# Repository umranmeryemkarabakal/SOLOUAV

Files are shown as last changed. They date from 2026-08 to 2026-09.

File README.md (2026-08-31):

# Tilt-Rotor VTOL — INDI + LESO + WLS Kontrolcü (MATLAB/Simulink)

3 tilt-rotorlu bir VTOL aracı (2 kanat rotoru + 1 kuyruk rotoru) için
**INDI (Incremental Nonlinear Dynamic Inversion)** tabanlı tutum kontrolcüsü,
**LESO** (Lineer Genişletilmiş Durum Gözlemcisi) ile bozucu telafisi,
**WLS** (ağırlıklı en küçük kareler) kontrol tahsisi ve tilt açısına bağlı
basit **gain-scheduling** içeren tam bir simülasyon paketi.

Depo iki paralel uygulama barındırır:

| | Saf MATLAB | Simulink |
|---|---|---|
| Kontrolcü | `indi_attitude_controller.m` | `sf_indi_rate_law.m` + `sf_wls_alloc.m` |
| Plant | `tiltrotor_plant_deriv.m` + `rk4_step.m` | `tiltrotor_plant_sfcn.m` (Level-2 S-Function) |
| Koşturma | `run_hover_gust_test.m`, `run_transition_test.m` | `tiltrotor_indi.slx` (`tiltrotor_indi_build.m` ile üretilir) |

İkisi de **aynı matematiği** uygular; Simulink tarafındaki `sf_*.m` dosyaları
MATLAB Function bloğunun kod üretimi kısıtlarına (değişken boyut yok,
`persistent` yok) göre yeniden yazılmış sürümlerdir.

---

## ► GÜNCEL DURUM (2026-08-31, Adım 152)

Bu README'nin gövdesi Adım ~39'da (3 Ağustos) donmuştur ve kontrolcü
mimarisini hâlâ doğru anlatır. Aşağıdaki blok o tarihten sonrasını özetler;
adım adım kayıt `WLS_LOCKUP_INVESTIGATION_REPORT.md`'dedir.

### Ne çalışıyor

Tam görev SITL'de uçuyor: **kalkış → ileri geçiş → sabit kanat (90° tilt,
~14,5 m/s) → geri geçiş → hover → iniş**, sakin ve rüzgârlı dünyada.
MATLAB regresyon 12/12, kod üretimi paritesi TEST A–F tam (0 mekanizma
eksik), üretilen kod kaynakla tutarlı, Cube Orange derleniyor (flash %84,5).

### Geometri (2026-08-31 itibarıyla)

| | değer |
|---|---|
| Ön rotorlar | x **+0,27**, y **±0,35**, z −0,11 |
| Kuyruk rotoru | x **−0,55**, z −0,07, tilt **0–20°** |
| Fin / rudder / çubuk | −0,78 / −0,87 / 0,71 m |

Ön naseller kanadın hücum kenarının **önüne** alındı: 90° tiltte pervane
diski dikey bir düzlemdir ve göbek hücum kenarının gerisindeyse kanadı keser.
Pervaneyi küçültmek, açıklıkta dışa almak ve tilt'i sınırlamak **ölçülüp
elendi** (Adım 143).

### ⚠ En büyük açık: kartta İNİŞ YOLU YOK

Modül `z_sp`'yi **dışarıdan** alır (`tiltrotor_indi_setpoint`) ya da manuel
gaz kolundan. İniş **dizisi** (kademeli alçalma, flare, temas, motor kesme)
`sitl/run_mission_test.py` içindedir — yani PC tarafında.

O betik hedefi `px4-mc_indi_tiltrotor test_sp` **POSIX kabuk istemcisiyle**
gönderir; bu yol yalnızca SITL'de vardır. Gerçek kartta karşılığı yoktur ve
`flight_mode_manager`/`mc_pos_control` bu airframe'de **bilerek durdurulur**
(yoksa iki modül aynı anda aktüatörlere yazar), yani PX4'ün kendi land modu
da devrede değildir.

**Sonuç: kart bugün flash edilirse otonom iniş olmaz.** Kartta tek yol
manuel gaz koludur (`_man_z_sp`) ve o da RC yoluna bağlıdır — madde H8,
**henüz sınanmadı**. Ayrıntı: `HARDWARE_READINESS_CHECKLIST.md`.

### Bu oturumda eklenen korumalar

- `LAND_TZ_MAX` — iniş kapısı altında tahsisat, komut edilen dikey kuvvetin
  2 katından fazlasını üretemez. Temas sonrası kuyruk 0 N'e dayanınca ön
  itkinin aracı geri kaldırmasını keser (ölçülen sıçrama 0,84 m).
- **Yer etkisi harmanı** — `lpos.vz`'nin yere yakın +0,4 m/s kalıcı sapması
  var (baro, rotor akışıyla basınçlanıyor) ve komut edilen alçalma hızını
  birebir iptal ediyordu. Yerde `z_deriv` ile harmanlanır.
- Kapılara üç denetim: gerçek mesh açıklığı, XML yorum, **köke bağlantı**
  (fin 20 mm havada asılıydı, hiçbir kapı görmüyordu).

---

## Araç ve model

Parametreler `tiltrotor_params.m` içindedir; kaynak olarak PX4/Gazebo
`tiltrotor_tailplane` airframe'i (SDF + `4022_gz_tiltrotor_tailplane`)
kullanılmıştır.

- Kütle 5 kg, `I = diag([0.2, 0.25, 0.25])` kg·m²
- 3 rotor, hepsi tilt edebiliyor (0 rad = hover / dikey, π/2 rad = cruise / yatay)
  - Rotor 0: sağ kanat, Rotor 1: sol kanat, Rotor 2: kuyruk (cruise'da pusher)
- Gövde ekseni **FRD** (X ileri, Y sağ, Z aşağı), konum NED
- Aktüatör dinamiği: rotor itkisi 1. derece gecikme (τ_up = 12.5 ms, τ_down = 25 ms),
  tilt servosu 1. derece gecikme (τ = 0.15 s) + 3 rad/s slew limiti

Plant modeli (`tiltrotor_plant_deriv.m`) 19 durumlu tam nonlineer 6-DOF'tur ve
basit bir boylamsal aerodinamik model içerir. **Kontrolcü bu aero modelini
bilmez** — bu bilinçli bir tasarım: aero etkiler INDI/LESO'nun telafi etmesi
gereken model belirsizliğini temsil eder.

---

## Görev profili (CONOPS) ve her evrenin bugünkü durumu

**HEDEF: TAM OTONOM GÖREV.** (2026-08-03'te gereksinim olarak netleştirildi.)
Pilot bu profilin sürücüsü değildir; pilot yolu yalnızca bir **müdahale/emniyet**
yoludur. Profilin kendisi baştan sona otomatik çalışmalı:

```
  kalkış: MULTİKOPTER
      ↓  (tilt ile ileri geçiş — OTOMATİK)
  seyir: SABİT KANAT / tilt motor
      ↓  (tilt ile geri geçiş — OTOMATİK)
  iniş:  MULTİKOPTER
```

Evre evre üç ayrı soru — ve bu üçünün karıştırılması engelleyici B1'in ta
kendisidir:

| evre | kontrol yasası var mı | SITL'de uçtu mu | **OTONOM tetikleniyor mu** |
|---|---|---|---|
| kalkış / hover | ✅ INDI + irtifa + `pos_hold` | ✅ | ⚠️ irtifa hedefi dışarıdan (`z_sp`) |
| **hover → seyir (ileri geçiş)** | ✅ **üç durumlu makine** (`forwardtrans_loop.m` / `forwardTransition()`, Adım 42). **İPTAL ETMEZ** (Adım 48, gereksinim) | ✅ **otomatik** | ✅ `ft_enable` |
| seyir | 🟠 **MATLAB'da kararlı, PX4'te hâlâ KISMİ.** SITL'de (PX4) kanat ağırlığın yalnızca %41-50'sini taşıyor. MATLAB'da hız döngüsü (Adım 47) + pitch trimi (Adım 49) + **ileri besleme (Adım 53)** ile **16-24 m/s zarfı kararlı**, kanat yük payı %75.6→%86.3, `Fz_sp` her hızda hedefte. Ama **hiçbiri PX4'e gönderilmedi**, ve tam kanat-taşımalı uçuş için Fx kanalına yüzey gerek — bkz. aşağısı | ✅ 14-20 m/s, tilt 32-72° | ⚠️ |
| **seyir → hover (geri geçiş)** | ✅ dört durumlu makine (B5, Adım 31-39) | ✅ otomatik | ✅ `bt_enable` |
| iniş / hover alçalma | ✅ | ✅ kademeli iniş | ❌ iniş dizisi test betiğinde, modülde değil |

**2026-08-03 (Adım 42): profilin tamamı ilk kez OTONOM uçtu** — iki bağımsız
uçuş, elle hiçbir komut yok, yalnızca iki bayrak (`ft_enable`, `bt_enable`):
kalkış → ileri geçiş (14.4 s rampa) → **tilt 44.1°, 15.2 m/s seyir** → geri
geçiş → hover → iniş. İrtifa sapması 0.58-0.80 m, itki doyumu %0.00, BIG_M 0,
NaN 0. Test: `sitl/run_mission_test.py`.

**Aynı fizik Adım 28'den beri uçuyordu; değişen, rampayı test betiğinin değil
ARACIN yürütmesi.** Bir yeteneğin var olması ile ona otonom erişilebilmesi ayrı
şeylerdir — engelleyici B1'in tamamı bu ayrımdır.

**🔴 VE SEYİR HENÜZ "SABİT KANAT" DEĞİL (Adım 43'te ölçüldü).** 14.4 m/s'de
kanat tilti 32°, kuyruk tilti 0.6°, ve **ağırlığın %59'u hâlâ rotorlarda.**
Zarf süpürüldüğünde (fx 12→24 N) tiltin 72°'ye yattığı ve 20.6 m/s'de her iki
**kanat rotorunun tamamen kapandığı** görüldü — ama kuyruk rotoru tek başına
21.8 N taşımaya devam ediyor ve tahsisat %20 doygun; bir kademe daha zarfı
kırıyor (%99.6 doygunluk, irtifa +21 m).

**Kök neden mimari:** `MulticopterIndiTiltrotor.cpp:1200` — kontrol yüzeyleri
(elevator/aileron/rudder, servo 0-4) **hiç oynatılmıyor**, sabit 0'da tutuluyor
("out of scope for the ported controller"). Dolayısıyla seyirde bütün duruş
otoritesi rotorlardan gelmek zorunda, rotorlar kapatılamıyor ve kuyruk rotoru
dik kalmak zorunda. **Tam kanat-taşımalı uçuş için kontrol yüzeyleri WLS
tahsisatına girmeli** (etkinlik matrisi 5×6 → 5×(6+N), yüzey etkinliği dinamik
basınçla ölçeklenir). Bu bir ayar değil, mimari bir adım.

**🆕 Adım 46 (2026-08-03) — 3. deneme MATLAB'da çalışıyor, ama PX4'e GİTMEDİ.**
Yüzeyler artık beş bağımsız aktüatör değil, **üç sanal aktüatör** (aileron =
antisimetrik elevon, elevator = simetrik servo_2/3, rudder); simetrik elevon
(flap) bilerek aktüatör değil. fx = 10 N'de 70 s, yüzeyler kapalı → açık:
ortalama tilt **52.1° → 70.6°**, kanat yük payı **%98.9 → %106.4**, toplam rotor
itkisi **24.0 → 16.1 N**, ve hız aktivitesi **iyileşti** (max |ω| 0.021 → 0.013).
Gereken sapmalar minik: −0.1° / −0.6° / +1.1°.

**Ama iki engel ölçüldü ve bu yüzden SITL'e gönderilmedi:**
(1) aileron, elevator olmadan açıkken ıraksıyor (iki ayrı fx'te tekrarlandı);
(2) fx ≥ 12 N'de rejim **yüzeyler kapalıyken bile** marjinal — kanat tilt'i 90°
mekanik durakta çakılı ve aracı yavaşlatan şey o durak. Yüzeyler bu kazara
korumayı kaldırıyor. Yani sıradaki iş yüzey değil, **aşağıdaki 1. madde**.
Detay: `sitl/WLS_LOCKUP_INVESTIGATION_REPORT.md` Adım 46.

**Ayrıca aynı adımda MATLAB plant'inde iki gerçek kusur bulundu ve düzeltildi:**
kanadın taşıma **işareti tersti** (15 m/s'de burun yukarı 43-67 N *aşağı*) ve
sürükleme ~7 kat fazlaydı (gz'de `cd = |cda·alpha|`, sabit değil). Plant artık
gz LiftDrag'in birebir portu (`aero_panels.m`, 5 panel, stall dahil) ve SITL'de
ölçülen kanat yük payını (%41-50) bağımsız olarak yeniden üretiyor.

**🆕 Adım 49 (2026-08-04) — TECS'in pitch yarısı yazıldı; 16 m/s'de büyük
kazanç, duvar duruyor, ve ASIL KISIT bulundu.** `cruise_pitch_loop.m`
(`θ̇ = −Ki·(Fz_sp − hedef)`, hız kapılı, ±6°). 16 m/s'de aynı kararlılıkla
tilt **37.7° → 60.7°**, kanat yük payı **%89.4 → %106.1**, kanat rotoru yükü
**6.71 → 2.46 N**. Ama 17 m/s üstünde pitch açık da kapalı da ıraksıyor —
ve **90 saniyelik çok yavaş bir rampa da kurtarmadı**, yani geçici rejim
değil.

**İlk deneme hedefi 0 aldı ("Fz_sp → 0 = tam kanat-taşımalı uçuş"). Yasa
çalıştı ve tam bu yüzden kırdı:** irtifa/hız sabit, tilt 41→65°, kanat
%93→%106, gereken pitch sadece 0.8° — sonra rotor itkisi tam **0.00 N**'e
değdi ve araç 2 s'de ıraksadı. Sebep yapısal: etkinlik matrisinde
`dτ/dδ ∝ T`, yani **itkisi sıfır olan tilt rotorunun otoritesi de sıfır**, ve
**Fx kanalının hiçbir yüzeyi yok**. Hedef ölçüme dayanarak −12 N'e alındı.

**Adım 50 — itki tabanı DENENDİ, GERİ ALINDI.** Kanat rotorlarına seyirde
`Tmin_cruise = 4 N` konuldu ve **daha önce kararlı olan noktayı bozdu**:
taban, rotorları **90° tiltte** itki üretmeye zorluyor; orada itki hiçbir
taşıma üretmez, sadece ileri kuvvet. Araç hızlanıyor → kanat fazla taşıyor →
irtifa döngüsü tek dikey aktüatörü (kuyruk rotoru) sıfıra kesiyor → `Fz_sp`
+96 N'e patlıyor. Geri alındı, geri alma birebir doğrulandı.

**Adım 51 — duvarın sebebi arandı: dört aday çürütüldü, sınır AÇIK.**
Çürüyenler: `wu_ele` (80/160/320/640), hız döngüsü kazancı (Kp 1/4/8), kanat
rotoru itki tabanı (daha kötü, geri alındı), seyir tilt tavanı (70/65/60°).
**Duruş kontrolü ıraksamaya kadar kusursuz** (θ setpoint'i birebir izliyor,
pitch talebi ~0.05, elevatör 0.11°, Fz_sp tam hedefte) — yani ne pitch
otoritesi ne tahsisat doygunluğu. Ölçülen mekanizma: tilt 56.7→64.8° kayarken
`T0` 5.13→0.38 N'e ölüyor, çünkü yüksek tiltte kanat rotorlarının dikey
etkinliği düşüyor ve tahsisat Fz'yi kuyruk rotoruna devrediyor.

Kanat oturma açısı `a0` **gerçek ama kısmi** bir katkı: yarıya indirmek
(0.0598→0.030) sınırı "16 kararlı / 17 ıraksıyor"dan "**17 kararlı** / 20
ıraksıyor"a taşıdı — ama orantılı değil (V_wb 1.41× arttı, sınır artmadı).

**🆕 Adım 52 — kuyruk aşağı yükü: sınırı ilk kez maddi olarak oynatan
müdahale, ve KALICI.** SDF kuyruk panellerini `a0 = −0.2` ile kuruyor; bu,
V² ile büyüyen kalıcı bir AŞAĞI kuvvet (25 m/s'de 34 N = ağırlığın %70'i) ve
kontrolcü onu **göremediği** için yükü sessizce **rotorlar** taşıyor. Tek bir
sabit elevatör ofseti tüm hızlarda iptal ediyor (iki terim de q̄ ile ölçekli):
`cla·a0 + rad_to_cl·δ = 0` → **δ = −4.54°**. Bu, madde (P)'nin `fx_trim`'inin
yüzey tarafındaki ikizi.

Ölçüm (v_sp = 17, trimsiz 29.9 s'de ıraksıyor): oran 0.4→32.3 s, 0.6→34.9,
0.8→75.6, **1.0→82.9 (2.8×)**, 1.3→73.7, 1.6→64.3 — **tepe tam olarak
analitik değerde**, yani sayı ayarlanmadı. 16 m/s çalışma noktasında da
kazanç: toplam rotor itkisi **16.13 → 14.14 N (−%12)**.

**Sınır o turda kalkmadı** (2.8× gecikiyor, kayboluyor değil). Detay: rapor
Adım 49-52.

**🆕 Adım 53 (2026-08-04) — DUVAR KALKTI. Eksik olan bir kazanç değil, bir
İLERİ BESLEME TERİMİYDİ.** Duvar ilk kez kanal bazında ölçüldü (her tick'te
WLS'in *istenen* ve *başarılan* sanal kontrolü ayrı kaydedildi) ve sebep tek
bir cümleye indi: **gereken trim zaten küçüktü ve sınırın çok içindeydi; yasa
oraya zamanında varamıyordu.** 19 m/s'de ıraksamadan hemen önce gereken
`theta` = **−0.71°** (sınır 6°, otoritenin %12'si), ulaşılan = **−0.59°**.
Ne otorite ne doygunluk sorunu vardı — **yarış kaybedilmişti**: yasa saf
integraldi (`tau` ≈ 19-24 s) ve hız 16 → 19 m/s'ye çıkarken gereken trim de
hareket ediyordu.

Doğru cevap **kendi test dosyamızın içinde** yazılıydı — `D2` denetimi Adım
49'dan beri gereken dengeyi elde türetiyordu:

```
theta_ff(V) = (W + Fz_hedef) / (qbar·S·cla) − a0
```

Bu ifade artık yasanın **içinde**; integral yalnızca **model hatasını**
kapatıyor. **`pitch_ki` DEĞİŞMEDİ** (5e-5) — kazanç ×4 de duvarı kaldırıyordu
(ölçüldü) ama irtifa döngüsünden 10× yavaş olma garantisini 3.5×'e düşürürdü;
ileri besleme aynı sonucu bedava veriyor ve `E1` denetimi `tau`yu hâlâ 17.5 s
ölçüyor.

Ölçüm (kapalı çevrim, hız + pitch + yüzeyler, 120 s):

| `v_sp` | ileri besleme YOK | **ileri besleme VAR** |
|---|---|---|
| 16 / 17 / 18 | kararlı | kararlı |
| **19** | **ıraksıyor, 39.8 s** | **kararlı** |
| **20** | **ıraksıyor, 39.4 s** | **kararlı** |
| 22 / 24 / 26 | — | **kararlı** |

Tilt 51.3° → 77.1°, `Fz_sp` her hızda tam hedefte (−11.8…−12.0 N), `T0` ≈
7.3 N, irtifa sapması 1.2 m. **26 m/s komut edilince araç ıraksamıyor,
24.9 m/s'de dengeye oturuyor** — çünkü orada hızı sınırlayan şey bir
kararsızlık değil `p.tecs.fx_max = 13 N`, yani kasıtlı bir emniyet tavanı.
Sınır bir arıza olmaktan çıkıp bir **tercih** oldu.

**İki dürüstlük notu:** (1) Adım 52'nin "17 m/s'de 82.9 s'de ıraksıyor"
ölçümü bu turun probe'unda yeniden üretilmedi — 17 ve 18 m/s 150 s boyunca
kararlı, ıraksama 19'da başlıyor; iki probe birebir aynı değil ve buradaki
sayılar **bu turun probe'una** aittir (mekanizma aynı). (2) Kuyruk trimi bu
kapalı çevrim rejiminde aşağı yükü **kaldırmıyor** (tahsisat sanal elevatörü
park edip trimi geri alıyor), ama yine de kritik: kapatıldığında 16 m/s'de
tilt 90° mekanik durağa yapışıyor ve 20 m/s 49.7 s'de ıraksıyor. Faydası
"yükü kaldırması" değil, **kontrolcünün modeli ile plant'in aynı şeyi
söylemesi.**

**HÂLÂ AÇIK: bu tam kanat-taşımalı uçuş DEĞİL.** `Fz_sp` hedefi −12 N olduğu
için rotorlar tasarım gereği ağırlığın ~%24'ünü taşıyor (kanat yük payı
%75.6 → %86.3). Bu bir kusur değil, Adım 49'un ölçülmüş kararı: sıfır itki
bir uçurumdur (`dtau/ddelta ∝ T`). Rotorların gerçekten kapanabilmesi için
**Fx kanalına bir yüzey** gerekir — bugün hiç yok. Detay: rapor Adım 53.

**Doğrulanmış çalışma zarfı: `v_sp` = 16-24 m/s** (16'da tilt 51.3°, 24'te
77.1°). Tümü MATLAB; **PX4'e gitmedi** (seyir katmanının PX4 karşılığı yok).

**🆕 Adım 48 (2026-08-04) — ileri geçiş artık İPTAL OLMUYOR.** Gereksinim:
profil tek parçadır ve ileri geçiş kendini kesmez (`FT_ALLOW_ABORT = false`).
İki emniyet dedektörü **silinmedi** — çalışmaya devam ediyor ve `warn_code` ile
loglanıyor; yalnızca eylemleri kalktı. Bedeli açık: Adım 29'un kaçış tırmanışı
artık otomatik tepki üretmez, sadece rapor edilir. Kazancı ölçülmüş: iptalin
garantili bir kaçış yolu **zaten yoktu** — iptal, geri geçişi *istemek* demekti
(Adım 30: `fx_sp = 0` aracı yavaşlatmıyor) ve sabitler sıfır marj bırakıyordu:
`FT_MIN_ALT(20) − FT_ALT_BAND(5) = 15 = BT_MIN_ALT`, yani **alçalarak** iptal
eden bir geçiş tam olarak kaçışının reddedildiği irtifada iptal ediyordu.
İptal geri getirilecekse önce o marj kapatılmalı. Detay: rapor Adım 48.

**🆕 Adım 47 (2026-08-03) — hız döngüsü kuruldu, ve ASIL DUVAR bulundu.**
`cruise_speed_loop.m` (PI, bumpless devralma, anti-windup) `fx`'i açık döngü
olmaktan çıkardı: v_sp = 16 m/s'de araç hedefi tutuyor (15.99) ve **tahsisat
doygunluğu %15.7 → %2.5**'e düşüyor. Ama v_sp ≥ 17'de hâlâ ıraksıyor, ve sebebi
ölçüldü — yüzeyler ya da ağırlıklar değil (`wu_ele` 8 kat değiştirildi, hiçbir
şey değişmedi):

```
theta = 0'da kanadın tam ağırlığı taşıdığı hız = sqrt(W/(0.5·rho·S·cla·a0))
                                               = 16.925 m/s
```

Yüzeysiz araç, fx ne olursa olsun (8/10/12/14 N) hep **16.85-16.90 m/s**'de
duruyordu — bu bir tilt durağı değil, o hızın kendisi. **Pitch setpoint'i her
yerde sabit sıfır**, oysa 16.9 m/s üstünde seviye uçuş negatif hücum açısı
ister. Yani TECS'in eksik yarısı **pitch (enerji dağılımı)**; itki yarısı
kuruldu. Tam kanat-taşımalı uçuş (rotorların kapanması) o yarım olmadan bu
hızın üstüne çıkamaz. Detay: rapor Adım 47.

**Otonomi için kalan diğer iki eksik:**

1. **Seyirde enerji yönetimi — İKİ YARI DA KURULDU (Adım 47 itki, Adım 49+53
   pitch), ama yalnızca MATLAB'da.** 16-24 m/s zarfı kapalı çevrim kararlı.
   Adım 29'un uyarısı (burun yukarı = tırmanma komutu) korunuyor: pitch yasası
   13 m/s'nin altında **tam sıfır otoriteli**. Kalan: **PX4'e port** ve
   ardından `sitl-lockup-check`.
2. **Evreleri zincirleyen bir görev dizicisi yok.** Evreleri hâlâ dışarıdan
   gelen iki bayrak zincirliyor. PX4'ün `navigator` / `flight_mode_manager`'ı bu
   airframe'de kasıtlı olarak durdurulmuş (bkz. `.post` betiği), yani diziyi
   modülün kendisi yürütmeli.

**İki önemli kavramsal not:**

1. **Buradaki "sabit kanat" PX4'ün fixed-wing modu DEĞİLDİR.** Bu airframe
   bilinçle `rc.mc_defaults` ile açılıyor (`rc.vtol_defaults` ile değil) ve
   kontrolcünün PX4'ün VTOL durum makinesinden haberi yok: seyir, *aynı INDI
   kontrolcüsünün* rotorları ileri eğip kanadın taşımaya başladığı hâlidir.
   Tilt açısını bir mod değişimi değil, WLS tahsisatı seçer. Gerekçe:
   `vtol_att_control` tilti açık çevrim komut ederdi ve bu, WLS'in kendi tilt
   kararıyla doğrudan çakışırdı.
2. **Tilti izlemek isteyen, geri geçiş testini izlemeli.** Pilot testinde
   (`run_pilot_input_test.py`) tilt havada yalnızca **3.7-15.1°** oynar — çünkü
   pilot dalı `fx_sp = 0` sabitler (madde (V)) ve araç saf multikopter uçar.
   Tavanın **45° → 9° → 20°** rampası yalnızca `run_backtrans_test.py`'de
   görülür; kamera için `INDI_GZ_CAM=side` en okunaklısıdır.

Açık maddeler ve donanım durumu için → `HARDWARE_READINESS_CHECKLIST.md`.

---

## Kontrol mimarisi

```
 att_sp ─┐
         ├─► [P tutum döngüsü]──► omega_sp ─┐
   att ──┘        (200 Hz)                  ├─► [P hız döngüsü] ──► omega_dot_des
                                     omega ─┘        (400 Hz)             │
                                                                          ▼
   omega ────────► [LESO 200 Hz] ──► d_hat ────────────────────────►  (−) çıkarma
                                                                          │
   omega_dot_ölçülen ──────────────────────────────────────────────►  (−) çıkarma
                                                                          ▼
                                                                    dtau = I·Δω̇
                                                                          │
   z_sp, z, vz ──► [irtifa P+PI, 50 Hz] ──► Fz_sp ──┐                     │
   Fx_sp ────────────────────────────────────────────┴─► F_sp ──┐         │
                                                                ▼         ▼
                                          u_actual ──► [G(u) Jacobian + WLS tahsisi]
                                                                ▼
                                                    u_cmd = [T0 T1 T2; δ0 δ1 δ2]
```

### 1. Kademeli tutum döngüsü
Dış P döngüsü tutum hatasından `omega_sp` üretir (yaw hatası sarmalanır,
±3 rad/s doygunluk), iç döngü `omega_dot_des` üretir. Kazançlar
`gain_schedule.m` ile ortalama tilt açısına göre smoothstep interpolasyonuyla
hover↔cruise arasında geçiş yapar — ayrı bir durum makinesi yoktur.

### 2. INDI artımlı kontrol yasası
```
Δω̇  = ω̇_des_telafili − ω̇_ölçülen
Δτ   = I · Δω̇
```
Model tersine çevirme yerine **ölçülen açısal ivme geri beslemesi** kullanılır;
dayanıklılığın kaynağı budur.

### 3. LESO bozucu telafisi
Eksen başına 2. dereceden gözlemci (`leso_axis_update.m`), bant genişliği
wo = 15 rad/s, kazançlar `β1 = 2wo`, `β2 = wo²` (`leso_bandwidth_gains.m`).
200 Hz'de desimasyonlu çalışır ve yalnızca etkin eksenlerde (varsayılan:
roll + pitch) devrededir.

> **Kritik ayrıntı:** Gözlemcinin "girişi" olarak telafi **sonrası**
> (`omega_dot_des_adj`) değer beslenir. Telafi öncesi değer beslenirse ESO
> kendi telafisini görmemiş gibi davranır ve `z2` sınırsızca sürüklenir.

### 4. WLS kontrol tahsisi
`effectiveness_matrix.m` her adımda **anlık** 5×6 Jacobian `G = ∂ν/∂u`
hesaplar (ν = [τx; τy; τz; Fx; Fz], u = [T0 T1 T2 δ0 δ1 δ2]). `wls_allocate.m`
kutu kısıtlı ağırlıklı en küçük kareler problemini active-set ile çözer:

```
min ‖Ws·(G·Δu − ν_des)‖² + ‖Wu·(Δu − Δu_pref)‖²   s.t.  Δu_min ≤ Δu ≤ Δu_max
```

**Ağırlıklar `Ws = diag([200 200 3 0.05 20])`** — bu değerler deneysel olarak
ayarlanmıştır ve bu airframe'e özgü iki tekillikle başa çıkar:

- **Yaw önceliği düşük (3):** Yaw otoritesi (diferansiyel tilt) roll ile aynı
  aktüatörü paylaşır; eşit ağırlık WLS'i roll↔yaw arasında sönümsüz bir limit
  cycle'a sokar.
- **Fx önceliği çok düşük (0.05):** Yaw'ı düzelten diferansiyel tilt aynı
  zamanda kayda değer bir Fx üretir. Fx = 0 hedefi roll/pitch mertebesinde
  ağırlıklandırılırsa δ1 rate limitinde salınır ve ψ referansa asla yakınsamaz.
  ~0.1'in altında bu çekişme tamamen kalkar.
- **Fz önceliği yüksek (20)** tutulabilir, çünkü irtifa hatası
  `altitude_loop.m` integrali tarafından ayrıca kapatılır.

`Wu` ağırlıkları tilt açısına göre planlanır: hover'da tilt sapması
`cos(δ)` üzerinden dikey itkiyi hızla düşürdüğü için tilt pahalıdır
(wu = 3.0), cruise'a doğru ucuzlar (1.5). Kuyruk rotoru merkez hatta olduğu
ve tilt yoluyla roll/yaw üretemediği için ×3 ek ceza alır.

> **2026-07-26 kısmi iyileştirme (kök neden HÂLÂ ÇÖZÜLMEDİ):**
> `wu_tilt_hover` eskiden 8.0'dı; hover trim itkisinde tilt roll üretiminde
> thrust'tan ~3.665× daha etkili olduğundan (`|dtau_ddelta0| ≈ 0.916` vs
> `|dtau_dT0| = 0.25`), 8.0 bu eşiğin üstünde kalıp WLS'i roll hatasını
> tilt yerine bir kanat rotorünü sıfıra kadar tüketerek kapatmaya
> itiyordu. `wu_tilt_hover` 3.0'a düşürüldü (eşik ~3.665) ve tilt
> kullanımı gerçekten arttı — **ama SITL doğrulamasında kilitlenme
> tamamen ortadan kalkmadı, sadece hangi rotorün kilitlendiği değişti**
> (T0 yerine T1) ve sistem birkaç saniye sonra sönümsüz salınıma girdi.
> Kök neden, ağırlık oranından önce `nu_des`'in neden kalıcı/büyüyen
> tek-işaretli kaldığında (LESO `d_hat` drift'i mi, `hoverTrim()`
> uyumsuzluğu mu) yatıyor. Ayrıca gerçek bir **mekanik model uyuşmazlığı**
> bulunup düzeltildi (`ROTOR_KM` 0.05→0.06, gerçek SDF `momentConstant`
> ile eşleşecek şekilde) — bu da tek başına yetmedi, ama farklı/daha
> uzun vadeli bir arıza modu (yaw ekseninde sınırsız savrulma, ~20s
> sonra) ortaya çıkardı. Sorun hâlâ AÇIK. Ayrıntı ve sonraki adım için
> `sitl/RUNBOOK.md` §4 "Aday çözüm 2" ve "Aday çözüm 3" bölümlerine bakın.

> **2026-07-27 GÜNCELLEME — kök neden bulundu ve düzeltildi (Adım 11):**
> Yukarıdaki paragraf tarihsel kayıttır; aradığı kök neden WLS
> ağırlıklandırmasında DEĞİLDİ. Gerçek sebep PX4 çıktı katmanındaydı:
> modül itki komutunu `motors.control[i] = u_cmd(i)/ROTOR_TMAX` ile
> **doğrusal** gönderiyordu, oysa Gazebo zinciri karesel
> (`w = 10 + control·1490` rad/s, sonra `T = 2e-5·w²`) — iki model
> yalnızca 45 N uç noktasında uyuşuyordu. Bu hem gerçek toplam itkiyi
> ağırlığın (49 N) altında bırakıyor hem de WLS'in etkinlik matrisini
> itkiye bağlı biçimde bozarak (gerçek `d(T)/du`: 5 N'da 0.23, 45 N'da
> 1.99; kontrolcü hep 1.0 sanıyordu) düşük itkili rotoru tabana iten bir
> **pozitif geri besleme** yaratıyordu. `thrustToNormalized()` ile
> karekök tersleme eklendi. Ayrıca `test_sp` setpoint'inin kontrolcüye
> hiç ulaşmadığı ikinci bir hata bulundu — yani önceki tüm SITL koşuları
> yanlış senaryoyu test etmiş. Düzeltmelerden sonra iki bağımsız koşuda
> (25s ve 40s) 6 m tırmanış ~0.15 m hatayla takip ediliyor, **hiçbir
> aktüatör kilitlenmiyor**, roll/pitch ≤0.5°. **Kalan tek açık sorun:**
> yaw. Tam anlatım → `sitl/WLS_LOCKUP_INVESTIGATION_REPORT.md` Adım 11.
>
> **2026-07-27 GÜNCELLEME #2 — ikinci kök neden (Adım 12):**
> `p.rotor.km` / `ROTOR_KM` işaretleri **FRD çerçevesinde tersti** (üç
> rotorda da). gz gövdeye `tau_z(FLU) = -turningDirection·T·km` uygular;
> FLU→FRD z çevrimiyle bu `+km·T` olur, model ise `m_i = km_i·T_i·dir_i`
> (`dir=(0,0,-1)`) ile `-km·T` diyordu. Sonucu: `hover_trim`'in yaw
> sıfırlayıcı diferansiyel tilt'i, rotor reaksiyon-torku dengesizliğini
> gidermek yerine **aynı yönde ekliyordu**. Adım 11 ile aynı sınıftan bir
> hata: **saf MATLAB bunu yapısal olarak göremez**, çünkü plant ve
> kontrolcü aynı `p.rotor.km`'yi paylaşır (ikisi birlikte yanlıştır).
> Düzeltme `[-0.06, +0.06, -0.06]` (MATLAB + Simulink + PX4) + `hover_trim`
> artık uygulanabilir (pozitif) tilt veren kanat rotorünü seçiyor.
> Etkisi: MATLAB regresyonu **iyileşti** (RMS p/q 0.0065/0.0015 →
> 0.0013/0.0004; transition max|omega| 0.0264 → 0.0126), SITL'de arm
> anındaki tepe yaw ivmesi **+6.5 → +0.47 rad/s² (14×)**.
> **Yaw hâlâ açık:** araç uçuş boyunca ort. +1.44 rad/s ile dönmeye devam
> ediyor. (Adım 11'in "±60° gezinme" ifadesi bir örnekleme artefaktıydı —
> yaw'ı açıdan değil **hızdan** ölçün.) Ölçülen mekanizma: tahsisat
> talep edilen yaw torkunun %6.8'ini üretebiliyor (tilt slew limiti) ve
> dış döngü dönerken yaw hız setpoint'ini sürekli ters çeviriyor.
> Ayrıntı → `sitl/WLS_LOCKUP_INVESTIGATION_REPORT.md` Adım 12.
>
> **2026-07-27 GÜNCELLEME #3 — YAW ÇÖZÜLDÜ (Adım 13):** Çözüm yaw'a
> otorite eklemek değildi. Dış attitude döngüsünün hız setpoint doygunu
> tek skalerdi (3.0 rad/s, üç eksen için); araç dönerken yaw hatası
> ±180°'de sarmalandığı için `omega_sp(3)` sürekli işaret değiştiriyor ve
> **zamanın yarısında iç döngü dönüşü sönümlemek yerine hızlandırıyordu**.
> Limit eksen bazlı yapıldı: `p.ctrl.rate_sp_limit = [3.0; 3.0; 0.5]`
> (MATLAB + Simulink + PX4). Sonuç: yaw hızı RMS 1.91 → **0.058 rad/s**,
> 25 s'de integre dönüş 1879° → **44°**, yerleşmiş yaw hatası **≤1.6°**;
> ayrıca roll/pitch hız RMS'i 30-65× ve irtifa hata RMS'i 0.456 →
> 0.211 m iyileşti. `yaw_sp = +30°` komutu 8 s'de, salınımsız izleniyor.
> **`sitl-lockup-check`'in üç kriteri de ilk kez aynı koşuda geçti.**
> **AMA — 2026-07-27 GÜNCELLEME #4 (Adım 16), bu sonucu daraltıyor:**
> yaw'ı asıl sönümleyen şey kontrolcü değil, ileri hızdaki aerodinamik
> rüzgâr gülü etkisiymiş. Tek uçuşta kontrollü ölçüm: 11.6 m/s'de +30°
> yaw adımı monoton ve temiz (~%13 aşım), **2.45 m/s'de ±25°'lik
> sönümsüz salınım**. Bu kontrolcüde yatay pozisyon döngüsü olmadığı ve
> araç yapısal ileri kuvvetle sürekli hızlandığı için (aşağıdaki madde)
> **bugüne kadarki tüm "hover" testleri aslında ~10 m/s seyir uçuşuydu**;
> gerçek anlamda yerinde duran hover — bir pozisyon kontrolcüsünün
> komut edeceği asıl durum — yaw için en kötü koşul ve orada kriter
> sağlanmıyor. Donanım durumu bu nedenle 🔴 NO-GO'ya geri alındı.
> Genel ders: zayıf otoriteli bir eksende dış döngü hız limiti, o eksenin
> gerçekten ulaşabileceği hızın ALTINDA tutulmalıdır — yoksa dış döngü iç
> döngünün sönümlemesini engeller.
> Yeni açık maddeler: hover'da yaw trim'i kaçınılmaz ileri kuvvet üretiyor
> (tilt aralığı [0°,90°] tek yönlü) → pozisyon döngüsü olmadığı için araç
> 25 s'de 235 m sürükleniyor; ve agresif adım-alçalmada rotorler ~68°'ye
> eğilip bir itki kanalı sıkışıyor. Ayrıntı → rapor Adım 13 ve §4 (L/N/O).
>
> **2026-07-28 GÜNCELLEME #5 (Adım 17) — Adım 16'nın MEKANİZMASI çürütüldü,
> ÖLÇÜMÜ duruyor.** Yeni `run_yaw_step_test.m` ile yaw adım yanıtı ilk kez
> saf MATLAB'da ölçüldü. Kritik nokta: bu plant'in aero modeli tamamen
> boylamsal olduğundan `M_aero(3) ≡ 0` — yani MATLAB **hiçbir hızda**
> aerodinamik yaw sönümlemesi üretmez, yaw açısından yapısal olarak "gerçek
> hover"dır. Buna rağmen ±30° adımı 3.1-3.7 s'de, **kalıcı salınım olmadan**
> oturuyor (son 5 s yaw hızı RMS ≤ 0.0001 rad/s; SITL'in aynı senaryosunda
> ±0.5 rad/s). Yani "düşük hızda rüzgâr gülü sönümlemesi kayboluyor" tek
> başına yaw sorununu açıklamıyor — SITL'e özgü ek bir kararsızlaştırıcı
> var ve aero sönümleme onu yalnızca maskeliyor. **En güçlü aday:** PX4
> portundaki `_u_actual` **açık çevrim gölge aktüatör modeli** (Gazebo'dan
> hiç geri besleme okumuyor), oysa MATLAB'da kontrolcü gerçek aktüatör
> durumunu görüyor — Adım 11 ve 12 ile aynı sınıftan bir kontrolcü/plant
> arayüz uyuşmazlığı. Destekleyen kanıt: iki ortam `TILT_RATE_MAX` 2.0↔3.0
> konusunda **ters işaretli** sonuç veriyor. Ayrıca **yaw adımının yön
> asimetrisi MATLAB'da yeniden üretildi ve sebebi kanıtlandı**: hover
> trim'de δ1 tek yönlü tilt aralığının tabanına (0°) çakılı olduğu için
> −yaw serbest, +yaw sürekli sınıra vuruyor (+30° aşımı `rate_max`=2.0'da
> %59.2, −30° %8.0). Ayrıntı → rapor Adım 17 ve §4 (Q)/(P).
>
> **2026-07-28 GÜNCELLEME #6 (Adım 18) — ölçüldü: gölge model şüphesi elendi,
> (P) ile (Q) tek köke bağlandı.** SITL'de düşük hızda (1.5-2.3 m/s) gerçek
> Gazebo tilt eklem açıları 250 Hz'de kaydedilip PX4'ün iç `_u_actual` gölge
> modeliyle karşılaştırıldı. Sapma **p99'da ≤ 0.55°** — aynı pencerede yaw
> **73.7°** bantta salınırken; yani gölge model gerçek bir katkı payı ama
> **baskın neden değil.** Buna karşılık koşu iki şey gösterdi: (1) **(Q) bir
> adım yanıtı kusuru değil, denge kararsızlığı** — sürekli salınım
> `yaw_sp = 0` iken oluşuyor (periyot 5.18 s, yaw hızı RMS 0.417 rad/s);
> (2) salınımın en güçlü korelatı **δ1'in tilt alt sınırından (0°) kalkıp
> geri çakılması** (salınım boyunca 12 olay, salınım durunca sıfır) — yani
> **(P) ve (Q) muhtemelen aynı kök nedenin iki görünümü: tek yönlü tilt
> aralığı.** Yan bulgu: gölge δ1/δ2 örneklerin %75/%97'sinde tam `0.000°`
> okurken gerçek eklemler 0.53°'de duruyor, dolayısıyla WLS bu eksenlerde
> 0.53°'lik gerçek hareket alanını göremiyor. Ayrıntı → rapor Adım 18.
>
> **2026-07-28 GÜNCELLEME #7 (Adım 19) — hız hipotezi de çürütüldü, (Q)
> nihayet doğru tarif edildi.** `yaw_sp` tüm uçuş boyunca 0'da sabit
> tutulup **yalnızca ileri hız** değiştirilen tek değişkenli bir A/B
> koşuldu. Salınım, yatay hız **2.00-2.09 m/s'de sabitken** söndü (yaw hızı
> RMS 0.439 → 0.006); hızlanma bundan *sonra* başladı. Yani **ileri hız,
> salınımı bitiren şey değil** — Adım 16'nın aerodinamik rüzgâr gülü
> mekanizması, Adım 17'nin MATLAB kanıtının yanına gelen ikinci bağımsız
> kanıtla çürütüldü. Dahası salınım **sönümsüz değil**: genlik düzenli
> biçimde sıfıra iniyor, **yerleşme süresi ~30-35 s**, iki bağımsız uçuşta
> tekrarlandı. Yani (Q) "kararsız yaw" değil, **çok zayıf sönümlü bir yaw
> modu** — ama bir pozisyon kontrolcüsü bu modu sürekli yeniden uyaracağı
> için hâlâ kabul edilemez. Adım 18'in önerdiği "tilt trim'ini ön-yükle"
> fikri de MATLAB'da çürütüldü: WLS'in amaç fonksiyonunda `du_pref = 0`
> olduğundan `Fx→0` hedefi δ1'i her tohumdan (bias 0/5/10°) aynı dengeye
> (δ0=9.00°, δ1=0.00°) geri itiyor. **Kalan tek nicel boşluk:** MATLAB aynı
> ±30° adımını 3.1-3.7 s'de oturtuyor, SITL ~8 s (adım) / ~33 s (arm
> geçicisi) alıyor — bu 2-10×'lik sönümleme farkı hâlâ açıklanmadı.
> Ayrıntı → rapor Adım 19 ve §4 (Q).
>
> **2026-07-28 GÜNCELLEME #8 (Adım 20) — yukarıdaki #7'nin iki çıkarımı GERİ
> ALINDI, ve (Q) nihayet üç uçuşla doğru tarif edildi.** Üçüncü bir uçuşta
> salınım 1.46-1.87 m/s'de **112 saniye boyunca hiç sönmedi** (Adım 19'un
> söndüğü uçuşta hız platosu 2.00-2.10 m/s idi). Yani sistem **kararlılık
> sınırında**: **<~2 m/s sürekli salınım, ~2 m/s marjinal, üstünde kararlı.**
> #7'deki "ileri hız sebep değil" ve "~30-35 s'de oturan zayıf sönümlü mod"
> ifadeleri tek uçuşa dayanan aşırı genellemelerdi; ikisi de geri alındı.
> Ayrıca yeni `run_yaw_ablation.m` ile SITL'in dört kusuru (PX4'ün açık
> çevrim gölge aktüatör modeli, `omega_dot` +8 ms gecikme, `omega_dot`
> gürültüsü, %25 `dt` jitter) MATLAB'a tek tek ve birlikte enjekte edildi:
> **hiçbiri yerleşme süresini değiştirmedi** (3.64-3.70 s). Yüksek hızın
> neden stabilize ettiği SDF'den türetildi: tek yanal yüzey olan dikey
> kuyruğun (alan yalnızca 0.032 m²) sönümleme türevi 2 m/s'de 0.27, 11.6
> m/s'de 9.1 Nm/rad — 34× — ve ±25-40°'lik salınımda yan kayma kuyruğun
> 19.4°'lik stall açısını aşıyor. **Ama aero, düşük hızdaki kararsızlığın
> kendisini açıklamıyor:** MATLAB'da hiç aero yaw momenti yokken sistem
> ζ≈0.4 ile rahatça kararlı. **SITL'de MATLAB'da bulunmayan, henüz
> bulunamamış bir kararsızlaştırıcı var** — araştırmanın açık merkezi bu.
> Ayrıntı → rapor Adım 20 ve §4 (Q).
>
> **2026-07-28 GÜNCELLEME #9 (Adım 21) — PX4 portunda GERÇEK BİR KOD HATASI
> bulundu.** Önce itki kanalı da elendi: gerçek Gazebo itkisi rotor eklem
> hızından türetilip (`T = 2e-5·(ω·20)²`; doğrulama: toplam 49.62 N ≈ ağırlık
> 49.05 N) gölge modelle karşılaştırıldı — sapma ~%0.1, yaw reaksiyon torkuna
> etkisi otoritenin %0.4'ü. Asıl bulgu tahsisat verimi ölçülürken çıktı:
> `MulticopterIndiTiltrotor.cpp:315-316, 324-325` **WLS'in slew kutusunu sabit
> `TS_CTRL = 1/400` ile boyutluyor**, oysa modül `vehicle_angular_velocity`
> callback'iyle **250 Hz'de** dönüyor (aynı fonksiyon `dt`'yi 171. satırda
> doğru hesaplayıp gölge model, LESO ve irtifa için kullanıyor). Ölçümle
> doğrulandı: `|ddelta|` p99 tam **0.00500 rad**, tick **4.00 ms**, tilt
> kanalları zamanın **%99.4-99.9**'unda doyumda, tahsisat yaw verimi **%20.6**.
> Sonuç: **efektif tilt slew tavanı 1.25 rad/s — hedeflenen 2.0'ın %62'si**, ve
> kanat tilt'i yaw'ın tek gerçek aktüatörü. Bu, Adım 11 (itki eşlemesi) ve
> Adım 12 (km işareti) ile **aynı sınıftan** bir hata: kontrolcünün varsayımı
> ile ortamın gerçeği uyuşmuyor, ve **saf MATLAB bunu yapısal olarak göremez**
> çünkü orada döngü gerçekten `p.Ts_ctrl` periyodunda koşar. Ayrıca Adım 14'ü
> geriye dönük açıklıyor (nominal 2.0 → efektif 1.25 çalıştı; nominal 3.0 →
> efektif 1.875 ıraksadı) ve **naif düzeltmenin zararlı olacağını öngörüyor**:
> kutuyu gerçek `dt` ile boyutlamak nominal 2.0'ı 2.0 efektif yapar, yani
> ıraksatan 1.875'in de üstüne. Ayrıntı → rapor Adım 21 ve §4 (Q).
>
> **2026-07-28 GÜNCELLEME #10 (Adım 22) — kutu ayrıştırıldı, davranış-nötr
> düzeltme SITL'de doğrulandı.** Önce bir düzeltme: #9'daki "kod hatası"
> nitelemesi fazla sertti — sabit periyot kullanmak jitter'a karşı **kasıtlı**
> bir korumaydı (kod yorumunda yazılı); gözden kaçan, nominal periyodun
> döngünün *gerçek* periyoduyla eşleşmesi gerektiğiydi. Yapılan: PX4'te
> `TILT_RATE_MAX` (2.0 rad/s) artık **yalnızca gölge modelin fiziksel servo
> limiti**; tahsisat kutusu ayrı bir sabit çiftine taşındı —
> **`TILT_SLEW_BOX_RATE = 1.25 rad/s` × `TS_BOX = 1/250`**. Bu ikisi aynı
> şey değildi: biri servonun *fiziksel olarak yapabildiği*, diğeri tahsisatın
> *tek tick'te isteyebileceği*. Sonuç tilt kutusunda 1 ULP farkla aynı
> (0.005 vs 0.0050000004), yani **davranış-nötr** — SITL'de doğrulandı:
> `|ddelta|` p99 hâlâ tam 0.00500 rad, itki doyumu %0.0, **aktüatör
> kilitlenmesi yok** (itki 8.26-19.10 N), `|vz|` ≤ 0.78 m/s, irtifa hata RMS
> 0.234 m. Yaw kriteri hâlâ kalıyor (37.09°) — bu değişiklikten değil, düşük
> hızdaki (Q) salınımından. **Kazanç davranışta değil, ölçülebilirlikte:**
> sabit artık gerçek rad/s anlamına geliyor ve taranabilir (1.25 çalışıyor,
> 1.875 ıraksıyordu — ilgi aralığı arası). MATLAB tarafına dokunulmadı
> (orada bu hata yapısal olarak yok). Ayrıntı → rapor Adım 22.
>
> **2026-07-28 GÜNCELLEME #11 (Adım 23) — ⭐ (Q)'NUN MEKANİZMASI BULUNDU.**
> Kutu hızını **uçuş içinde** değiştirebilen bir test kancası (`slewbox`)
> eklenip iki koşuda, **ters sıralarda**, her değerde aynı +30° yaw adımı
> uyarımıyla tarandı. Adımın son 5 s'sindeki yaw hızı RMS:
>
> | kutu (rad/s) | koşu A | koşu B | test edilen hız | sonuç |
> |---|---|---|---|---|
> | **1.25** (eski) | 0.583 | 0.466 | 2.20 / 0.86 m/s | **salınıyor** |
> | 1.50 | 0.391 | 0.005 | 2.02 / 2.00 m/s | marjinal |
> | **1.75** | 0.0037 | 0.0051 | 1.35 / 2.76 m/s | **sakin** |
> | **2.00** | 0.0056 | 0.0055 | 0.81 / 3.14 m/s | **sakin** |
>
> **Hız kesin olarak elendi:** 1.25 hem 0.86 hem 2.20 m/s'de salınıyor,
> 1.75/2.00 ise 0.81-3.14 m/s aralığının tamamında sakin. Yani düşük hızdaki
> yaw salınımı **kontrol yasasında bir sönümleme eksikliği değil, tahsisatın
> tilt slew'undan aç bırakılmasıymış.** MATLAB çapraz kontrolü de tutuyor:
> onun efektif kutusu `3.0·(1/400)` @ gerçek 400 Hz = **3.0 rad/s**, yani
> denenen her değerin üstünde, ve orada aşım %24.1 / yerleşme 3.69 s — trend
> düzgün ekstrapole oluyor. Adım 14 çelişmiyor, **açıklanıyor**: o, kutuyu ve
> gölge modelin fiziksel limitini *birlikte* oynatmıştı; #10'daki ayrıştırma
> kutunun tek başına yükseltilmesini mümkün kılan şey. Varsayılan
> **1.25 → 1.75** yapıldı (fiziksel limite 0.25 rad/s pay). Doğrulama:
> kilitlenme ✅, dikey hız ✅ (0.816 m/s), roll/pitch ✅ (±0.06°); **yaw
> kriteri hâlâ ❌** (tepe 35.80° vs 37.09°) — kalan aşım arm geçicisinin tek
> seferlik salınımı, asıl kazanç **kalıcı salınımın yok olması (RMS ~0.5 →
> ~0.005, 100×)**. Ayrıntı → rapor Adım 23.
>
> **2026-07-28 GÜNCELLEME #12 (Adım 24) — "gölge modeli gerçek servoya sadık
> kıl" DENENDİ, GERİ ALINDI.** SDF'den gerçek servo: `JointPositionController`
> p_gain=100, cmd_max=2 N·m, eklem sürtünmesi 1.0 N·m, etkin atalet
> J=0.0168 kg·m². İki türetilmiş sayı: **Coulomb ölü bandı =
> friction/p_gain = 0.573°** ve max ivme 59.4 rad/s². Ölü bant, #9'da ölçülen
> kalıcı 0.52-0.53°'lik ofseti niceliksel açıklıyor. Çevrimdışı doğrulamada
> (kayıtlı komut dizisi → gerçek eklem açısı) gölge-gerçek hata RMS'i:
> 1. derece 0.287/0.408/0.554° → **tam 2. derece 0.414/0.462/0.553° (DAHA
> KÖTÜ)** → **1. derece + ölü bant 0.082/0.051/0.0040° (3.5×/8.0×/139× daha
> iyi)**. Yani sadakat açığının tamamı sürtünme ölü bandıymış; atalet birkaç
> ms'de oturduğu için 2. derece dinamik 250 Hz'de alâkasız. **Ama
> uygulandığında kapalı çevrimde KİLİTLENDİ:** `u_cmd = u_actual + du` komutu
> gölgeye bağlıyor, `du` ise slew kutusuyla 0.40° ile sınırlı — ölü banttan
> küçük — dolayısıyla hiçbir tick sürtünmeyi kıramıyor, gölge ve komut birlikte
> donuyor (SITL: üç tilt de tüm uçuş donuk, yaw bandı 238°, araç dönüyor).
> Geri alındı, baseline doğrulandı. **İki ders:** (1) *açık çevrim replay,
> kapalı çevrim geri besleme tuzağını gösteremez* — çevrimdışı doğrulama kendi
> içinde doğruydu ve yine de ölümcül sorunu kaçırdı; (2) *artımlı allocator
> mimarisi gölgenin komuta sürünmesini zorunlu kılıyor*, stiction bununla
> temelden uyumsuz. Ayrıntı → rapor Adım 24.
>
> **2026-07-28 GÜNCELLEME #13 (Adım 25) — "arm geçicisini kaynağında küçült"
> yolu da kapandı; premis iki kez çürüdü, kod değiştirilmedi.**
> (1) *Tilt ön-konumlandırma gereksiz:* disarm'da servolar NaN alıyor ve 0°'de
> duruyor, arm'da gölge δ0 ≈ 9.39°'de tohumlanıyor — gerçek bir 9.39°'lik
> başlangıç uyuşmazlığı var, ama **gerçek δ0 trim'in %90'ına 72 ms'de
> ulaşıyor** ve +0.20 s'de gölgeyle 0.16° içinde örtüşüyor; oysa yaw hızı
> *saniyeler* boyunca birikiyor. Zaman ölçekleri uyuşmuyor.
> (2) *Trim itkiden bağımsız geçerli:* makul görünen "diferansiyel tilt hover
> itkisine göre boyutlanmış, tırmanışta reaksiyon torku büyüyünce bozulur"
> hipotezi yanlış — **`τ_tilt = −Σ py·T·sin δ` de içinde `T` taşıyor**, tıpkı
> `τ_react = −Σ km·T·cos δ` gibi; ikisi birlikte ölçekleniyor ve oran
> korunuyor (itki 49.7 → 68.9 N çıkarken NET tork −0.021 → −0.011 N·m).
> **Sonuç: ayrı bir "arm geçicisi" mekanizması yok** — arm sonrası savrulma
> madde (Q)'nun kendisi, zayıf yaw ekseninin 0.03-0.15 N·m'lik artık torklara
> yanıtı (tahsisat yaw otoritesi adım başına ~0.033 N·m). **Genel ders: bir
> dengesizliğin "ölçekle bozulduğunu" iddia etmeden önce, onu dengeleyen
> terimin aynı ölçekle büyüyüp büyümediğine bakın.** Ayrıntı → rapor Adım 25.
>
> **2026-07-30 GÜNCELLEME #14 (Adım 37) — geri geçişin FREN YASASI düzeltildi;
> Adım 31'in "doğrulandı" kaydı marjinalmiş.** Mevcut tilt geçişleri Gazebo
> arayüzü açık şekilde yeniden koşuldu (yeni `INDI_SITL_GUI=1` anahtarı) ve
> manevra **iki bağımsız uçuşta devir hızının üstünde takıldı**: v_h 3.2-3.5
> m/s'de 90+ s kararlı denge, `BT_HANDOFF_V = 3.0`'a hiç inemedi, `pos_hold`
> hiç istenmedi. Ölçülen sebep: `pitch = BT_PITCH_MAX·v_h/BT_BRAKE_V_FULL`
> hızla **sönüyor**, ama yenmesi gereken ileri kuvvet **sönmüyor** — δ1/δ2
> `TILT_MIN`'de çakılı olduğu için (madde (P)) yaw trimi δ0'ı 10-15°'de tutuyor
> ve kalıcı 3.1-4.1 N üretiyor; yalnızca *durmak* için gereken açı
> `asin(fx_trim/(m·g)) = 3.39°`, `BT_PITCH_MAX = 4°`'nin hemen altında.
> İlk düzeltme (`BT_BRAKE_V_FULL` → `BT_HANDOFF_V`) **yetmedi** — ikinci uçuş
> bu kez 4.9 m/s'de takıldı, çünkü otorite (3.42 N) bozucunun dağılımının
> (3.1-4.1 N) tam içinde. **Asıl düzeltme yasayı AYRIŞTIRMAK:**
> `pitch = asin(FX_TRIM/(m·g))` (sönmez, duruş trimi) `+ BT_PITCH_MAX·fade`
> (sönen frenleme payı). İki doğrulama uçuşu: 15.38/14.66 m/s → 0.13/0.07 m/s,
> BRAKE evresi 92-99 s'lik takılmadan **5.7-6.1 s**'ye indi, yaw −3.4/+1.1°,
> irtifa bandı 1.11-1.14 m, itki doyumu %0.00, 0 BIG_M; MATLAB regresyonu tam
> nötr, zorunlu `sitl-lockup-check` geçti. **Genel ders: bir kontrol yasasını
> "bozucu" ve "otoritem" diye ayrıştırın — burada bozucu sabitti, otorite
> sönüyordu ve tek terimli yazıldığı için bu uyumsuzluk görünmüyordu.**
> Ayrıntı → rapor Adım 37.
>
> **2026-08-03 GÜNCELLEME #15 (Adım 39) — madde (S) kapatıldı: bir eşik,
> yasasının KONTROL ETTİĞİ ekseni okumalı.** `BRAKE → HANDOFF` koşulu
> `v_h < BT_HANDOFF_V` idi ve `v_h` bir BÜYÜKLÜK; fren yasası ise yalnızca gövde
> ileri eksenini kontrol ediyor ve yanal eksende HANDOFF'a kadar hiçbir kontrol
> yok. Ölçülen arıza (Adım 38, log 14_13_11): `min|v_h| = 3.08` iken `u = −0.51`,
> yanal `v = +3.04` — araç ileri yönde durmuştu, eşiği tutan şey manevranın
> kaldıramadığı bileşendi; handoff hiç istenmedi, sönmeyen fren pitch'i araç
> **geri yönde 12.8 m/s**'ye kaçana kadar itti. Düzeltme iki terimli:
> (1) çıkış **işaretli** `v_fwd < BT_HANDOFF_V` okur (`v_fwd < 0` da geçerli
> çıkıştır), (2) frenleme marjı `max(0, v_fwd)` ile söner, yani geri giderken
> marj SIFIRDIR — **kaçışı fiilen durduran terim budur.** RETRACT bilerek
> büyüklükte kaldı: oradaki soru aerodinamiktir ("kanat hâlâ taşıyor mu").
> İki normal + bir kancalı uçuş, plantsız durum makinesi testi (13/13, ve eski
> mantığın aynı izde 300 s takıldığı gösterildi), nötr MATLAB regresyonu,
> `sitl-lockup-check` geçti. **Ama kancalı uçuş rejimi HİÇ KURMADI** (yanal
> yalnızca 1.28 m/s), o yüzden asıl kanıt yeni bir probe'dan geldi
> (`probe_lateral_handoff.py`, frenlerken heading +90°): yanal 4.76 m/s,
> HANDOFF `|v_h| = 5.04`'te oldu — **eski koşul o anda sağlanmıyordu.**
> **Ve probe benim kendi ölçütümde aynı hatanın dördüncüsünü buldu:** madde
> (S)'yi yakalasın diye eklediğim "işaretli ileri hız ≥ −2.0" ölçütü KALDI
> (−3.95) ama araç kaçmamıştı — heading 186.7° dönmüştü ve `v_fwd` DÖNEN bir
> çerçeveye izdüşüm. Ölçüt çerçeveden bağımsız hâle getirildi (fren
> penceresinde yeniden-hızlanma ≤ 1.0 m/s) ve **gerçek arıza log'una karşı**
> doğrulandı (10.31 m/s → KALDI). **Genel ders: bir ölçüt de bir kontrol yasası
> kadar sinyal seçer ve aynı hatayı yapabilir; ölçütü geçmesi gereken uçuşlarda
> değil, KALMASI gereken uçuşta sınayın.** Ayrıntı → rapor Adım 39.

### 5. İrtifa dış döngüsü
`altitude_loop.m`: P (pozisyon) + PI (dikey hız, anti-windup clamp), 50 Hz.
Sabit `Fz_sp = −m·g` kullanıldığında uzun hover'da tilt kaynaklı dikey itki
kaybı telafi edilemiyor ve irtifa düşüyordu; integral terim bunu kapatır.

---

## Çalıştırma

### Saf MATLAB (Simulink gerekmez)

```matlab
cd('tiltrotor_Matlab files')
run_hover_gust_test      % hover'da bozucu reddi, LESO açık vs kapalı
run_transition_test      % hover -> cruise tilt geçişi
run_yaw_step_test        % yaw adım yanıtı (+-30 derece), aşım/yerleşme/salınım
run_yaw_ablation         % SITL kusurlarını enjekte eden ablasyon (tanı aracı)
```

Hepsi konsola metrik yazar ve klasöre PNG kaydeder (`hover_gust_test.png`,
`transition_test.png`, `yaw_step_test.png`, `yaw_ablation.png`).

- **`run_hover_gust_test`** — t = 4 s'de roll ekseninde yavaş değişen sentetik
  bir bozucu moment ve bir rüzgar esintisi (kontrolcünün bilmediği aero model
  üzerinden pitch bozucusu) uygulanır. LESO açık/kapalı iki koşu karşılaştırılıp
  bozucu penceresindeki RMS p/q hataları raporlanır.
- **`run_transition_test`** — `Fx_sp` 12 s'de 0 → 10 N rampalanır. WLS'in
  rotorları kendiliğinden öne yatırması ve gain-scheduling'in tilt açısıyla
  birlikte kayması gösterilir.
- **`run_yaw_step_test`** — t = 4 s'de `yaw_sp = ±30°` adımı, 25 s. Yaw
  ekseninin en kötü koşulunu ölçer: bu plant `M_aero(3) ≡ 0` olduğu için
  **hiçbir hızda aerodinamik yaw sönümlemesi üretmez** (SITL'de yaw'ı asıl
  sönümleyen şey ileri hızdaki rüzgâr gülü etkisi — bkz. yukarıdaki Adım
  16/17 notları). Metrikler: aşım %, ±2° yerleşme süresi, kalıcı hata ve
  **kalıcı salınım göstergesi** (son 5 s yaw hızı RMS). Her iki yönü de
  koşar, çünkü yanıt yön-asimetriktir. PX4 portuyla aynı tilt slew
  limitinde koşmak için:
  `setenv('YAW_TEST_TILT_RATE_MAX','2.0'); run_yaw_step_test`
- **`run_yaw_ablation`** — tanı aracı (Adım 20). SITL'de olup MATLAB'da
  olmayan kusurları tek tek ve birlikte enjekte eder: PX4'ün **açık çevrim
  gölge aktüatör modeli**, `omega_dot` taşıma gecikmesi, `omega_dot`
  gürültüsü, kontrol adımı jitter'ı. Amaç, SITL'in düşük hızdaki yaw
  kararsızlığını MATLAB'da yeniden üretebilen kusuru bulmak. **Hiçbir
  kontrol sabitini değiştirmez.** Şu ana kadarki sonuç: dördü de etkisiz —
  yani aday listesi hâlâ eksik.

Her iki betik de kontrolü 400 Hz'de, fiziği RK4 ile 5 alt-adımda (2 kHz)
entegre eder.

### Simulink

```matlab
tiltrotor_indi_build     % tiltrotor_indi.slx'i sıfırdan programatik kurar
sim('tiltrotor_indi')    % veya Simulink'te Run
```

`tiltrotor_indi_build.m` blokları ekler, MATLAB Function bloklarının içeriğini
`sf_*.m` dosyalarından yükler, hatları bağlar ve modeli kaydeder. Çözücü:
sabit adım `ode4`, `FixedStep = 0.0025` (400 Hz).

Modeldeki iki tasarım kararı:
- **Unit Delay bloğu (`u_cmd_delay`)** — plant'in doğrudan-besleme çıkışı WLS
  üzerinden girişine döndüğü için oluşan cebirsel döngüyü kırar; aynı zamanda
  gerçek donanımdaki bir adımlık hesaplama gecikmesini doğru temsil eder.
- **Durum, Unit Delay ile dışarıdan geri beslenir** — MATLAB Function blokları
  içinde `persistent` kullanmak sürekli örnekleme zamanıyla çelişir. Bu yüzden
  `sf_indi_rate_law` LESO/filtre durumunu 13×1 vektör olarak, `sf_altitude_loop`
  integralini skaler olarak dışarı verir.

---

## Bilinen sınırlamalar

- **MATLAB referansında pozisyon/hız dış döngüsü yok.** Orada sadece irtifa
  kapalı çevrimdir; `Fx_sp` elle verilir ve `run_transition_test` tam bir
  hover→cruise geçiş kontrolcüsü değil, iç döngünün değişen tilt açısına
  tepkisinin gösterimidir. **PX4 tarafı bunu geçti:** Adım 28'de yatay pozisyon
  döngüsü (`positionLoop`, hover-only, 3 m/s'de kapılı) ve Adım 31-39'da
  dört durumlu geri geçiş makinesi eklendi. **Ama hover→cruise yönü hâlâ bir
  KONTROLCÜ değil, bir `fx_sp` girdisidir** — ve pilot onu komut edemiyor
  (madde (V), yukarıdaki CONOPS tablosu).
- **Yaw otoritesi zayıf.** Airframe'in kendisinden gelen bir kısıt (diferansiyel
  tilt roll ile aynı aktüatörü kullanıyor); yaw kasıtlı olarak yavaş ve düşük
  öncelikli tutulmuştur.
- **`omega_dot` doğrudan modelden okunuyor** (tek kutuplu α = 0.3 filtresiyle).
  Gerçek uçuşta bu bir IMU türevidir; gürültü/gecikme modellenmemiştir.
- **Aero modeli basit** — yalnızca boylamsal (X-Z), sabit `Cd`, yanal
  aerodinamik yok.
- **`sf_wls_alloc.m` active-set yerine büyük-M ceza yöntemi** kullanır (kod
  üretimi için sabit boyut gerekliliği). Aynı sonuca yakınsar ama birebir aynı
  algoritma değildir.
- Simulink'te irtifa döngüsü 50 Hz yerine 400 Hz'de çalışır (blok örnekleme
  zamanını programatik ayarlama sorunu); integral örnekleme hızından bağımsız
  olduğu için matematiksel olarak eşdeğerdir.

---

## Dosya yapısı

Dosya ve klasörlerin tek tek açıklaması için bkz. **`dosya_ve_klasor_yapisi.md`**.

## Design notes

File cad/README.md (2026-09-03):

# Gazebo modelinden CAD (STEP)

`tiltrotor_indi` Gazebo modelini SolidWorks / Fusion 360'ta açılabilen
parametrik katı gövdelere çevirir.

```
cad/
├── build_tiltrotor_cad.py   üretici betik (cadquery)
├── sdf_mesh.py              COLLADA okuma + düzlem kesiti + loft hazırlığı
├── dogrula.py               bağımsız denetleyici — STEP çıktısını SDF'e karşı sınar
├── dogrulama_raporu.txt     son denetim çıktısı (dogrula.py üretir)
├── render_onizleme.py       üç görünüş önizlemesi üretir
├── onizleme.png             üç görünüş doğrulaması
├── build_mechanism.py       mekanizma üreticisi (tilt grubu, iniş takımı, menteşe/tahrik)
├── dogrula_mekanizma.py     mekanizmanın bağımsız denetleyicisi
├── fusion_01_import.py      Fusion 360'a parçaları içe aktarma betiği (Aşama 1)
├── fusion_02_joints.py      11 revolute eklemi SDF'ten kurma betiği (Aşama 2)
├── dogrula_fusion_parser.py Aşama 2'nin SDF ayrıştırıcısını rapora karşı sınar
├── MONTAJ.md                eklem tablosu, montaj adımları, imalat kısıtları
└── step/
    ├── tiltrotor_assembly.step   23 gövdenin tamamı (tek dosya)
    └── parts/*.step              parça başına ayrı dosya
```

## Neden yeniden inşa, neden doğrudan dönüşüm değil

SDF bir CAD dosyası değildir. Modelde geometri iki biçimde duruyor:

- **üçgen mesh** (`x8_wing.dae`, `x8_elevon_*.dae`, `iris_prop_*.dae`) — Fusion'a
  "mesh body", SolidWorks'e "graphics body" olarak girer; kalınlık profili,
  menteşe hattı, parametre taşımaz;
- **kutu ve silindir** (kuyruk kirişi, tailplane, fin, elevatör, rudder, pylon,
  motor) — atalet ve çarpışma için konmuş kaba hacimler.

Bu yüzden dosya "çevrilmedi", ölçüleri korunarak **yeniden inşa edildi**:

| Parça | Yöntem |
|---|---|
| `wing` | `x8_wing.dae`'den 60 açıklık istasyonunda gerçek kesit alınıp loft |
| `winglet_left/right` | Uç bölgeden 20 düşey (z) kesit, loft |
| `elevon_left/right` | `x8_elevon_*.dae`'den 14 kesit, loft |
| `rotor_*` | `iris_prop_cw.dae`'den 61 kesit, loft — pala burulması korunur |
| `tailplane`, `vertical_stabiliser` | SDF kutu zarfına oturtulmuş NACA simetrik profil |
| `elevator_*`, `rudder` | Yuvarlak hücum kenarlı, sivri firar kenarlı flap kesiti; menteşe ekseni yuvarlak burnun merkezinden geçer |
| `motor_*`, `pylon_*`, `tail_boom`, `tailplane_strut` | SDF'teki silindir/kutu ölçüleri birebir |

Kuyruk yüzeylerinin profili SDF'te **yok** — orada yalnızca kutu var. Kutunun
kiriş/açıklık/azami kalınlık zarfı korunarak içine simetrik profil oturtuldu;
bu bir varsayımdır, sim geometrisinden bir sapma değil ama ondan da fazlasıdır.

## Yeniden üretme — İKİ AŞAMA, sırası önemli

```bash
python3 -m venv env && ./env/bin/pip install cadquery
./env/bin/python cad/build_tiltrotor_cad.py    # 1) aerodinamik gövdeler (mesh ister)
./env/bin/python cad/build_mechanism.py        # 2) mekanizma (mesh İSTEMEZ)
```

**Sıra bağlayıcıdır.** Aşama 2, Aşama 1'in ürettiği STEP gövdelerini okur ve
bazılarını değiştirir (pylon'lara motor süpürme boşluğu, ana yüzeylere menteşe
boşluğu). Aşama 1'i tek başına koşmak bu boşlukları geri alır ve motor kendi
pilonunun içinden geçmeye başlar — `dogrula_mekanizma.py` bunu yakalar.

Mesh dizini varsayılan olarak
`~/PX4-Autopilot/Tools/simulation/gz/models/standard_vtol/meshes`;
`VTOL_MESH_DIR` ortam değişkeniyle değiştirilebilir. Mesh'ler PX4 ağacında
yoksa doğrudan indirilebilir:

```bash
BASE=https://raw.githubusercontent.com/PX4/PX4-gazebo-models/main/models/standard_vtol/meshes
for M in x8_wing x8_elevon_left x8_elevon_right iris_prop_cw iris_prop_ccw; do
  curl -sL -o "$M.dae" "$BASE/$M.dae"
done
```

### Mekanizma neden ayrı bir betikte

`build_mechanism.py`'nin ürettiği hiçbir parça mesh'e ihtiyaç duymaz —
hepsi SDF'ten türeyen eksenler etrafında kutu ve silindirdir, menteşe
boşlukları da mevcut STEP gövdelerinden kesilir. Böylece mesh'i olmayan bir
makinede de mekanizma yeniden üretilebilir ve denetlenebilir.

Menteşe sayıları burada da tekrarlanmaz: betik `fusion_02_joints.py`'nin
ayrıştırıcısını ödünç alır (`dogrula_fusion_parser.py` ile aynı teknik).

Kaynak model: `Tools/simulation/gz/models/tiltrotor_indi/model.sdf`
(depodaki `tiltrotor_tailplane_model.sdf` ile birebir aynı).

## Başka bir makinede devam etme

Depo **kendi başına yetmez**: üretim zinciri üç şeye daha ihtiyaç duyar ve
üçü de bilerek depo dışında tutulur (bkz. CLAUDE.md). Yeni makinede sırayla:

**1. cadquery (depo dışında ayrı venv)**
```bash
python -m venv ~/cadquery-env
~/cadquery-env/bin/pip install cadquery
```
Sistem Python'una kurmayın; bu depo numpy/tensorflow çakışması olan
ortamlarda çalışıyor.

**2. Mesh'ler (depo dışında)**
```bash
mkdir -p ~/vtol_meshes && cd ~/vtol_meshes
BASE=https://raw.githubusercontent.com/PX4/PX4-gazebo-models/main/models/standard_vtol/meshes
for M in x8_wing x8_elevon_left x8_elevon_right iris_prop_cw iris_prop_ccw; do
  curl -sL -o "$M.dae" "$BASE/$M.dae"
done
export VTOL_MESH_DIR=~/vtol_meshes
```
Doğruluk kontrolü: yeniden üretilen `winglet_left` **417,3 cm³**,
`elevon_left` **125,3 cm³** çıkmalı. Tutmuyorsa mesh sürümü farklıdır.

**3. Fusion MCP köprüsü (isteğe bağlı, yalnız Claude'un Fusion'ı sürmesi için)**
```bash
git clone https://github.com/ndoo/fusion360-mcp-bridge.git ~/fusion360-mcp-bridge
python -m pip install --user "mcp<2" httpx        # ⚠ mcp<2 ŞART
python -c "import secrets; print(secrets.token_hex(32))" > ~/.fusion-mcp-secret
# fusion-addin/FusionMCPBridge -> Fusion AddIns klasörüne kopyala
```
⚠ **`mcp>=1.0.0` kurmayın.** pip en son major'ı (2.x) çeker, orada `FastMCP`
→ `MCPServer` olarak yeniden adlandırılmış ve köprünün `server.py`'si v1 API
kullanıyor; sonuç `ModuleNotFoundError` ve Claude tarafında sessiz
`CONNECTION_CLOSED`.

Fusion'da eklentiyi açmak: **Shift+S** → *Eklentiler* sekmesi →
`FusionMCPBridge` → *Çalıştır*. Sağlık kontrolü:
```bash
curl -H "Authorization: Bearer $(cat ~/.fusion-mcp-secret)" http://127.0.0.1:7654/health
```

`.mcp.json` **depoda izlenmez** — içinde makineye özgü mutlak yollar vardır,
her makinede yeniden yazılmalıdır. MCP sunucuları yalnızca oturum
açılışında yüklenir; dosyayı yazdıktan sonra Claude Code'u yeniden başlatın.

**4. Fusion çizimi** Autodesk bulutundadır (Fusion Team). Aynı hesapla
oturum açınca doküman gelir; depoda `.f3d` tutulmaz — eklemler zaten
`fusion_02_joints.py` ile `model.sdf`'ten yeniden kurulabilir.

**Tek dosyada tüm model:** `cad/step/tiltrotor_assembly.step` (74 parça,
mekanizma dahil). Aşama 2 tarafından yazılır; Aşama 1'in yazdığı sürümde
yalnızca 23 gövde parçası vardır.

## Fusion 360'a aktarma

```
Fusion 360 > Utilities > Scripts and Add-Ins > Scripts > + > cad/fusion_01_import.py
```

Boş bir Design açıp çalıştırın. Betik 23 parçayı ayrı bileşen olarak içe
aktarır ve 12 sabit parçayı `base_link` adlı Rigid Group'a alır. Parçalar
mutlak konumda üretildiği için occurrence dönüşümü birim matris kalır — araç
kendiliğinden doğru oturur, hizalama gerekmez.

**Parça klasörü otomatik bulunur.** Sırayla denenen yerler: `TILTROTOR_CAD_PARTS`
ortam değişkeni, `~/Documents/tiltrotor_cad/step/parts`,
`~/tiltrotor_project_updates/cad/step/parts`, `~/SOLOUAV/cad/step/parts`.
Hiçbiri tutmazsa betik durur ve denediği yolları listeler; o zaman dosyanın
başındaki `BASE` değişkenine tam yolu yazın.

Betik iki çalıştırma yolunu da destekler: Fusion'ın Scripts paneli `run(context)`
çağırır; MCP köprüsünün `fusion_execute`'u ise kodu düz `exec` eder ve `run()`'ı
kimse çağırmaz — dosyanın sonundaki koruma bu ikinci durumu yakalar.

Başlamadan önce üç şeyi kontrol eder ve gerekirse durur: klasör bulundu mu, 23
STEP dosyasının hepsi yerinde mi, bu Design'da aynı adlı bileşenler zaten var mı
(ikinci kez çalıştırma kopya üretmesin diye).

### Aşama 2 — eklemler

```
Scripts > + > cad/fusion_02_joints.py      (Aşama 1'den sonra, aynı Design'da)
```

11 hareketli parça için revolute eklem kurar: 3 tilt (kanat rotorları 0…90°,
kuyruk **0…20°**), 3 serbest pervane, 5 kumanda yüzeyi (elevon ±44,7°,
elevatör ve rudder ±29,8°).

**Menteşe sayıları betiğe yazılmaz — `model.sdf`'ten okunur.** Bu depo aynı
sayının birden çok yerde ayrışmasından zarar gördü; eklem tablosunu dördüncü bir
kopya olarak tutmak aynı hatayı tekrarlamak olurdu. Betik SDF yolunu da otomatik
arar (`TILTROTOR_SDF` env değişkeni, sonra parça klasörüyle aynı adaylar).

Kurmadan önce kontrol eder: SDF bulundu mu, 11 eklem çıktı mı, gerekli
bileşenler var mı, bu Design'da zaten eklem var mı. Parçalar mutlak konumda
olduğu için menteşe noktası her iki bileşende de aynı yere inşa edilir ve eklem
kurulurken hiçbir şey yerinden oynamaz.

**Ayrıştırıcı ayrı bir kapıyla sınanır** — Fusion içinde cadquery
kullanılamadığı için betik SDF'i kendi regex'leriyle okur, yani ayrıştırma
mantığının ikinci bir kopyası vardır:

```bash
python3 cad/dogrula_fusion_parser.py     # bağımlılık yok, sistem python3'ü yeter
```

11 eklemin nokta/eksen/limit değerlerini `dogrulama_raporu.txt` [5] bölümüyle
karşılaştırır. Geliştirilirken iki **gerçek ve sessiz** hatayı yakaladı:
SDF'te link adları çift, eklem adları tek tırnaklı olduğu için elevatör ve
rudder menteşesi 790–870 mm kaymıştı; `<inertial>` içindeki poz kütle merkezi
olduğu halde link yerleşimi sanıldığı için elevon menteşesi tam 300 mm
kaymıştı. Kapının ikisini de yakaladığı, hatalar kasten geri konularak
doğrulandı.

## Bilinen sapmalar

- **Winglet ucundaki loft taşması giderildi** (1 Eylül 2026, ÇÖZÜLDÜ).
  Winglet kesitleri sağlamdı (dolgu 0,67-0,77); sorun veterin son 7 mm'de
  111 → 68 → 20 mm'ye çökmesi ve `makeLoft(ruled=False)`'un pürüzsüz yüzeyi
  son kesitin **ötesine** sürüklemesiydi: gövde 207,2'de bitmesi gerekirken
  211,2 mm'ye uzanıyordu. O uzantı kendi kendini kesen ince bir dilimdi —
  görünürde kanat ucundan fırlayan bir artık. Üst 8 mm'deki dilim
  genişlikleri `0,0 111,8 0,0 0,0 0,0 110,4 109,3 0,0` ile bunun düzgün bir
  katı olmadığı ölçüldü. Boolean kırpma yine kararsız çıktı (`Bnd_Box is
  void`), o yüzden `close_winglet_tip` taşmayı kırpmak yerine **kaynağında**
  engelliyor: son istasyon atılıp 205,5-207,7 mm arasına çeyrek elips kapak
  konuyor, loft'un ekstrapole edecek yeri kalmıyor. Sonuç: zmax **207,7 mm**
  (tam zarf), dilim genişlikleri `111,7 110,4 107,8 101,0 79,2 69,7 63,7 7,0`
  ile tek yönlü.
- **Winglet'ler kanatla tek gövdeye kaynatılmadı.** Tabanları kanat ucunun
  içine oturur (z = −5 mm) ama ayrı katı olarak kalır; OCC'de bu birleşme
  ya hacmi şişiriyor ya sıfıra çöküyordu. Montajda ikisini `Rigid Group`
  yapın, ya da CAD içinde birleştirin.
- **Kanat mesh'i 3.5 mm eksantrik** geliyordu (bbox y = −1071.9 / +1078.9);
  açıklık ortasına kaydırılıp sağ yarı sol yarının aynası olarak üretildi.
- **`base_link_collision` kutusu üretilmedi.** O, kanadın 135 mm altında duran
  bir çarpışma vekilidir, araca ait bir parça değildir.
- **Pervane çarpışma diski (r = 100 mm) ile görsel mesh (r = 129 mm) uyuşmuyor.**
  CAD'de görsel mesh esas alındı; SDF'teki çarpışma silindiri daha küçüktür.
- **CCW pervaneler CW mesh'inden aynalanarak üretildi.** `iris_prop_ccw.dae`
  kesitleri pala boyunca kendini kesiyor (61 kesitin 23'ü) ve loft geçersiz
  katı veriyor; `iris_prop_cw.dae` aynı ayarlarla temiz. CCW pervane zaten
  CW'nin aynasıdır; iki mesh arasındaki fark yalnızca pala faz açısıdır
  (bbox'ları ~4 mm kayık), o da dönen bir pervanede anlamsızdır.
- Pervanelerin **eksen etrafındaki başlangıç açısı** mesh'ten geldiği gibidir;
  SDF bir başlangıç açısı tanımlamıyor.
- **Dış pala kesitleri yeniden inşa edildi** (1 Eylül 2026, ÇÖZÜLDÜ).
  `iris_prop_cw.dae` bir **görsel** mesh'tir; dış palada kabuk 0,2 mm'ye,
  en uçta 0,01 mm'ye iner. O kadar inceyi dilimleyince kontur kendi üstüne
  katlanıyordu: uç yüzeyinin alanı kendi sınırlayıcı kutusunun %3-6'sıydı
  (profilde ~%65) — "pervane ucu oval değil" şikâyetinin kaynağı buydu.
  `rebuild_thin_sections` ölçülen **veter, burulma ve kesit merkezini
  korur** (bunlar istasyondan istasyona düzgün değişiyor, yani güvenilir),
  yalnızca konturu elipsle ve kalınlığı `PROP_MIN_T = 1,2 mm` imalat alt
  sınırıyla yeniden kurar. Sonuç: bozuk istasyon **18 → 0**, uç yüzeyi
  0,50 → **8,65 mm²**, dolgu oranı 0,07 → **0,65**. Bedeli: pervane hacmi
  4,61 → 7,57 cm³ (dış pala kalınlaştı) — bu bilinçli bir imalat kararıdır,
  sim geometrisinden bir sapmadır. Önce denenip elenen dört onarım yolu
  `build_tiltrotor_cad.py` içindeki not bloğunda.
- **Pala uçları yuvarlatıldı** (1 Eylül 2026). Loft son istasyonda bitince
  OCC ucu **düz** bir yüzle kapatıyordu, pala küt kesilmiş görünüyordu
  (uçtan 0,3 mm'de kesit alanı zaten 10,1 mm²). `round_blade_tips` her iki
  uca çeyrek elips kapak koyar. Kapak DIŞARI eklenmez, mevcut ucun içine
  oturtulur — yoksa pervane çapı 256,7 → 264,2 mm büyür. Kapak boyu
  (`PROP_TIP_CAP = 18 mm`) uç veterinden türetilmez: uçta veter 4,4 mm ama
  18 mm içeride 20 mm, o yüzden kısa kapak (4/8/12 mm denendi) alanı
  sıçratıyor. Sonuç: alan 0,9 → 3,9 → 6,7 → 9,1 → 11,3 diye kademeli
  açılıyor, açıklık 256,7 mm korunuyor.
- **Pervane dalgalanması giderildi** (1 Eylül 2026). `smooth_stations`, 61
  mesh kesitini açıklık boyunca yumuşatır. Ölçüm: veter dizisindeki yön
  değişimi **15/59 → 3/59**. Sıra bağlayıcıdır: önce yumuşatma, sonra
  yeniden inşa — tersi durumda yumuşatma yeni elipsi katlanmış
  komşularıyla ortalayıp bozulmayı geri getiriyor.
- **Kuyruk menteşe hattında 11 mm boşluk** (1 Eylül 2026, AÇIK). Ölçüm
  (`BRepExtrema`, asgari mesafe): elevon↔kanat **0,17 / 0,56 mm** (doğru),
  ama elevatör↔tailplane ve rudder↔fin **11,0 mm**. Sebep zinciri tam:
  menteşe cebi 6 mm yarıçaplı yani **12 mm çaplı**, tailplane ise **12 mm**
  kalın — silindir levhayı boydan boya kesiyor, firar şeridi gövdeden
  kopuyor, kopan parça düşüyor ve gövde eksenden 16 mm geriye çekiliyor
  (bbox x −780 → −749,2). Fin'de (20 mm) aynı mekanizma.

  **Denenip elenen çözümler:**
  1. Cep yarıçapını ana gövdenin yarım kalınlığıyla sınırlamak — kopmayı
     çözüyor (tailplane x −780'e geri dönüyor, cepten 51 yerine 7,6 cm³
     alınıyor) ama çakışmayı temizlemiyor: elevatör∩tailplane **4,69 cm³**,
     rudder∩fin **3,32 cm³**. Parçalar iç içe kalıyor, yani dönemezler —
     11 mm boşluktan daha kötü, geri alındı.
  2. Ana gövdeyi menteşe düzleminin arkasından kırpmak — sınırsız kutuyla
     kanadı yıkıyor (29465 → 18030 cm³). Kutu kumanda yüzeyinin açıklık
     aralığıyla sınırlandığında ise Aşama 1 segfault verdiği için sonuç
     doğrulanamadı.

  **Reçete (bir sonraki oturum için):** iki kısıt AYNI ANDA sağlanmalı —
  cep yarıçapı ana gövdenin yarım kalınlığından küçük (kopmasın) VE burun
  yarıçapı + kaçıklık payından büyük (çakışma kalmasın). Tailplane'de yarım
  kalınlık 6 mm olduğundan: **burun 4,5 mm, cep 5,5 mm, artı açıklıkla
  sınırlı arka kırpma.** Her adımdan sonra `dogrula_mekanizma.py`.

- **Elevonlar birbirinin aynası değil** (1 Eylül 2026, AÇIK). İki elevonun
  pozu SDF'ten **bağımsız** alınıyor (`ELEVON` tablosu), aynalanarak
  üretilmiyor. Ölçüm: sağ elevon açıklıkta **8,0 mm**, veterde 0,9 mm kaymış;
  hacimler 125,28 / 126,08 cm³. Kanat için "sağ yarı solun aynası" işlemi
  uygulanmış, winglet'ler de simetrik (417,81 / 417,82 cm³) — elevonlar bu
  işlemden geçmemiş tek çift. Menteşe boşluğu yarıçaplarının asimetrik
  çıkmasının (20,09 / 25,19 mm) sebebi budur.

## Doğrulama

```bash
/path/to/cadquery-venv/bin/python cad/dogrula.py > cad/dogrulama_raporu.txt
/path/to/cadquery-venv/bin/python cad/render_onizleme.py     # onizleme.png
```

`dogrula.py` üretici betiğin tablolarını **kullanmaz**; SDF'i baştan ayrıştırır,
böylece elle aktarma hataları da yakalanır. Sekiz denetim: kapsam, ölçü, mesh
zarfı, katı sağlığı, menteşe, duruşta girişim, tilt süpürmesi, yüzey sapması.

Çıktı dört sınıfa ayrılır ve **yalnızca ilki bir CAD hatasıdır**:

| sınıf | anlamı |
|---|---|
| `HATA` | STEP çıktısı SDF ile uyuşmuyor — üretici betik düzeltilmeli |
| `MODEL` | CAD doğru, **SDF geometrisinin kendisi** çakışıyor |
| `UYARI` | çalışma aralığında kalan, incelenmesi gereken girişim |
| `limit dışı` | eklem `<upper>` sınırının ötesi; araç o açıya gidemez |

İki denetim **eşik seçimiyle** çalışır, ikisi de kasıtlı:

- **Tilt süpürmesi** eklem tavanını SDF'ten okur (`joints[jn]['upper']`). Kuyruk
  rotoru 30°'den sonra çubuğa girer ama tavan 20°'dir, dolayısıyla o açılar
  bulgu değil `limit dışı` sayılır. Satırlar yine basılır: limit ileride
  gevşetilirse bedelinin ne olacağı kayıtlı kalsın diye.
- **Yüzey sapması** mutlak hacimle değil **ortalama film kalınlığıyla** yargılar
  (`FILM_TOL = 0,05 mm`). Elevon kanatla aynı loft yüzeyinden kesildiği için
  ikisi duruşta zaten yüzey olarak çakışık; 0,5 m açıklıkta 0,01 mm'lik bir film
  bile 0,7 cm³ hacim yapar. Mutlak hacim eşiği bu yüzden büyük parçalarda
  ölçtüğü şeyi değil parçanın boyutunu yansıtır.

### Aşama 2 artık idempotent (3 Eylül 2026'da düzeltildi)

`build_mechanism.py` istenildiği kadar tekrar koşulabilir. İki ardışık koşum
61 parçanın hacim + sınır kutusu tablosunu **birebir aynı** üretir ve kapı
ikisinde de `61 geçti, 2 uyarı, 0 HATA` verir.

**Eskiden neden çökerdi** (bilgi kaybolmasın diye duruyor): betiğin girdisi
kendi çıktısıydı — `load_part()` de export da `step/parts/` dizinine bakardı.
İkinci koşuda betik, burnu zaten silindire tıraşlanmış bir kumanda yüzeyine
yeniden burun eklemeye çalışır ve `Null TopoDS_Shape object` ile çökerdi.
`git checkout -- cad/step/` ile "temiz duruma dönmek" de kurtarmazdı, çünkü
depodaki STEP'ler Aşama 2'nin ÇIKTISIDIR.

**Düzeltme:** girdi çıktıdan ayrıldı. Aşama 2'nin üzerine yazdığı 10 gövde
(`build_mechanism.py` → `TURETILEN`) artık `step/parts_pristine/` altındaki
dokunulmamış kopyadan okunur; oraya Aşama 1 yazar. `step/parts/` yalnızca
çıktıdır. Kopya eksikse betik ne yapılacağını söyleyerek durur.

`parts_pristine/` depoda izlenir (4,2 MB): mesh'siz bir makinede Aşama 2'nin
koşabilmesi buna bağlı.

### Mekanizma kapısı

```bash
/path/to/cadquery-venv/bin/python cad/dogrula_mekanizma.py
```

`dogrula.py`'nin mekanizma karşılığı: üretici betiğin tablolarını kullanmaz,
STEP'leri ve SDF'i baştan okur. Beş denetim — katı sağlığı, tilt süpürmesi
(SDF limitleri boyunca), kumanda yüzeyi hareketi, iniş takımı bağlantısı,
duruşta istenmeyen girişim.

Geliştirilirken üç **gerçek** hata yakaladı: (1) pylon'lara süpürme boşluğu
açmayı unutmuştum, motor üç nacelle'de de kendi pilonundan geçiyordu;
(2) elevatör servoları `tailplane_strut`'ın içindeydi (5,24 cm³);
(3) kuyruk dikmesi tailplane'i kesiyordu. Ayrıca kapının kendisinde bir
boşluk vardı: yüzeyleri yalnızca ana gövdelerine karşı sınıyordu, o yüzden
elevatörün **kuyruk çubuğuna** çarpmasını ıskalıyordu — komşu gövdeler eklendi.

Son durum: **61 geçti, 2 uyarı, 0 HATA.** İki uyarı elevatörün +29,8°'de
kuyruk çubuğuna girmesidir; temiz sınır **~±25°**. Not: `MONTAJ.md`'deki
+26° mekanik durdurucu ölçümle 0,02 cm³ girişime izin veriyor.

---

Son durum (`dogrula.py`): **62 geçti, 2 uyarı, 0 CAD hatası, 0 kaynak model
bulgusu, 5 limit dışı.** 23 STEP dosyasının hepsi `BRepCheck_Analyzer` ile geçerli ve tek
kapalı katı. Kalan 2 uyarı elevatör–kuyruk çubuğu girişimidir; bilerek açık
bırakıldı ve montajda çözülecek (bkz. `MONTAJ.md`, imalat kısıtı bölümü).

Ana ölçülerin SDF/mesh karşılaştırması `MONTAJ.md` sonundadır.

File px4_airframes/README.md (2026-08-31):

# PX4 airframe dosyaları

Kart ve SITL yapılandırması. Bunlar PX4 ağacında yaşar; buradaki kopyalar
**depoyu kendi kendine yeterli** kılmak içindir (`gz_model/` ile aynı gerekçe).

| dosya | nerede yaşar | ne |
|---|---|---|
| `4023_gz_tiltrotor_indi{,.post}` | `init.d-posix/airframes/` | SITL |
| `14002_tiltrotor_indi{,.post}` | `init.d/airframes/` | gerçek kart |
| `14003_tiltrotor_indi_hitl{,.post}` | `init.d/airframes/` | **HITL** (madde H6) |

## 14003 nasıl çalışıyor

14002'yi **kopyalamaz, kaynak gösterir** (`. ${R}etc/init.d/airframes/14002_tiltrotor_indi`).
Airframe betikleri `rc.autostart` tarafından `.` ile source edilir, yani source
zinciri çalışır. Böylece çıkış fonksiyonları, tilt servo ölçekleri ve `.post`
durdurma listesi tek yerde kalır; iki dosyanın ayrışması imkânsızdır.

Üstüne yalnızca HITL farkları gelir: `SYS_HITL 1`, `HIL_ACT_FUNC1..11`,
emniyet devre kesiciler (`CBRK_SUPPLY_CHK`, `CBRK_IO_SAFETY`, `UAVCAN_ENABLE 0`),
`COM_RC_IN_MODE 1`.

## SYS_HITL tek başına yetmez

PX4 kaynağından okundu (tahmin değil): HIL'i fiilen açan şey
`Commander::instantiate()` içindeki `argv[1] == "-h"` kontrolüdür
(`Commander.cpp:2669`), parametre okuması değil. `SYS_HITL > 0`, `rcS`'in
(satır ~342) şu dalını tetikler:

```sh
pwm_out_sim start -m hil     # gerçek PWM yerine HIL kanalları
sensors start -h             # gerçek sensörler yerine HIL_SENSOR
commander start -h           # HIL_STATE_ON -- asıl anahtar
param set GPS_1_CONFIG 0     # gerçek GPS kapatılır
```

## ⚠ Sessiz tuzak: datarate

`Mavlink::set_hil_enabled()` HIL akışlarını **yalnızca `_datarate > 5000`**
ise açar (`mavlink_main.cpp:666`). Bağlantı yavaşsa HIL sessizce açılmaz —
hata da vermez.

- USB (`/dev/ttyACM*`): datarate 100000'e sabitlenir → sorun yok
- UART: `datarate = baudrate / 20`. 921600 → 46080 ✅, **57600 → 2880 ❌**

Yani HITL'i düşük baud'lu bir telemetri linki üzerinden kurmayın.

## Kullanım

```bash
# kartta
param set SYS_AUTOSTART 14003
param save
reboot

# bilgisayarda (SITL gz koşarken)
cd hitl && python3 gz_hil_bridge.py --dev /dev/ttyACM0 --baud 921600
```

## Hâlâ açık

`pump_actuators()` **bilerek yazılmadı**: kanal eşlemesi artık biliniyor
(`gz_hil_bridge.py`, `HIL_CHANNELS`) ama **ölçek** bilinmiyor — PX4 normalize
(0..1) gönderir, gz motor modeli rad/s bekler. Tahminle yazmak Adım 11'in
bedelini tekrarlamak olur. Kart bağlandığında ilk iş `log_actuator_scale()`
ile ham `controls[]` değerlerini kaydedip ölçeği **ölçmek** (madde K4).

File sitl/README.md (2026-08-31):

# SITL test tooling — mc_indi_tiltrotor

> **Çalıştırma adımları (adım adım komutlar + beklenen çıktı)** → [RUNBOOK.md](RUNBOOK.md)
>
> **Güncel kontrol durumu ve açık sorunlar** →
> [WLS_LOCKUP_INVESTIGATION_REPORT.md](WLS_LOCKUP_INVESTIGATION_REPORT.md)
> dosyasının başındaki **"► BURADAN BAŞLAYIN"** bloğu (2026-07-28, Adım 17).
> Kısaca: aktüatör kilitlenmesi ✅ çözüldü, yaw'ın sınırsız dönmesi ✅
> çözüldü, **ama yaw ekseni gerçek (düşük hızlı) hover'da hâlâ sönümsüz**
> — donanım için 🔴 NO-GO.
>
> **Adım 17 (2026-07-28) teşhisi değiştirdi:** saf MATLAB'da aynı yaw adımı
> **salınımsız oturuyor**, üstelik MATLAB plant'i hiçbir hızda aerodinamik
> yaw momenti üretmediği hâlde (`M_aero(3) ≡ 0`). Yani sorun "düşük hızda
> aero sönümlemenin kaybolması" değil — **SITL'e özgü** bir kararsızlaştırıcı
> var. Yeni MATLAB referans testi: `../run_yaw_step_test.m`.
>
> **Adım 18 (2026-07-28) ölçtü ve kökü daralttı:**
> - Gölge `_u_actual` ile gerçek Gazebo eklem açısı arasındaki sapma
>   **p99'da ≤ 0.55°** — aynı pencerede yaw 73.7° bantta salınırken. Yani
>   gölge model **baskın neden DEĞİL** (Adım 17'nin şüphesi elendi).
> - **(Q) yeniden üretildi ve yeniden çerçevelendi:** salınım `yaw_sp = 0`
>   iken oluyor → bir *adım yanıtı* kusuru değil, **denge kararsızlığı**.
> - **En güçlü korelat: δ1'in `TILT_MIN=0` sınırından kalkıp geri çakılması**
>   → **(P) ve (Q) muhtemelen aynı kök: tek yönlü tilt aralığı.**
>
> **Adım 19 (2026-07-28) hız hipotezini de çürüttü:** `yaw_sp = 0` sabit
> tutulup yalnızca ileri hız değiştirilen tek değişkenli A/B'de salınım,
> hız **2.00-2.09 m/s'de sabitken** söndü → **ileri hız salınımı bitiren
> şey değil.** Ayrıca salınım **sönümsüz değil, ~30-35 s'de oturan çok
> zayıf sönümlü bir mod** (iki uçuşta tekrarlandı). Kalan tek nicel boşluk:
> MATLAB aynı adımı 3.1-3.7 s'de oturtuyor → **2-10× sönümleme farkı**,
> sebebi SITL'e özgü ve açıklanmadı. Çıktı: `yaw_airspeed_ab.png`.
>
> **Adım 21 (2026-07-28) — GERÇEK KOD HATASI:**
> `MulticopterIndiTiltrotor.cpp:315-316, 324-325` WLS'in slew kutusunu sabit
> `TS_CTRL = 1/400` ile boyutluyor, ama modül **250 Hz'de** dönüyor (aynı
> fonksiyon `dt`'yi 171. satırda doğru hesaplıyor). Ölçüldü: `|ddelta|` p99 tam
> **0.00500 rad**, tick 4.00 ms, tilt `sat_flag` **%99.4-99.9**, tahsisat yaw
> verimi **%20.6** → **efektif tilt slew tavanı 1.25 rad/s (hedeflenen 2.0'ın
> %62'si)**. Kanat tilt'i yaw'ın tek gerçek aktüatörü.
> ⚠️ **Naif düzeltme zararlı olabilir** — nominal 2.0'ı 2.0 efektif yapar, ki
> Adım 14'te ıraksatan efektif 1.875'in üstündedir. İtki kanalı temiz çıktı
> (sapma ~%0.1).
>
> **Adım 22 (2026-07-28) — KALICI DEĞİŞİKLİK, davranış-nötr, doğrulandı:**
> tahsisat kutusu ile fiziksel servo limiti ayrıştırıldı.
> `TILT_RATE_MAX = 2.0` artık yalnızca gölge modelin fiziksel limiti;
> tahsisat kutusu **`TILT_SLEW_BOX_RATE = 1.25 rad/s` × `TS_BOX = 1/250`**
> (tilt kutusu 1 ULP farkla aynı). SITL doğrulaması: `|ddelta|` p99 hâlâ tam
> 0.00500 rad, itki doyumu %0.0, kilitlenme yok, `|vz|` ≤ 0.78 m/s, irtifa
> hata RMS 0.234 m; yaw hâlâ (Q) nedeniyle kalıyor (37.09°).
> *Not: Adım 21'in "kod hatası" nitelemesi fazla sertti — sabit periyot
> jitter'a karşı kasıtlıydı; eksik olan periyodun gerçek döngü hızıyla
> eşleşmesiydi.*
>
> **⭐ Adım 23 (2026-07-28) — (Q)'NUN MEKANİZMASI BULUNDU.** `slewbox <rad/s>`
> test kancasıyla kutu **uçuş içinde** tarandı (iki koşu, ters sıra, her
> değerde aynı +30° yaw adımı). Adımın son 5 s yaw hızı RMS'i:
> **1.25 → 0.583/0.466 (salınıyor)**, 1.50 → 0.391/0.005 (marjinal),
> **1.75 → 0.0037/0.0051 (sakin)**, **2.00 → 0.0056/0.0055 (sakin)**.
> 1.25 hem 0.86 hem 2.20 m/s'de salınıyor; 1.75/2.00 ise 0.81-3.14 m/s'nin
> tamamında sakin → **hız değil, kutu hızı ayırt edici.** Yani düşük hızdaki
> yaw salınımı **tahsisatın tilt slew'undan aç bırakılmasıymış.**
> Varsayılan **1.25 → 1.75** yapıldı. Doğrulama: kilitlenme ✅, dikey hız ✅
> (0.816 m/s), roll/pitch ✅; yaw hâlâ ❌ (tepe 35.80° vs 37.09°) — kalan
> aşım arm geçicisi, kalıcı salınım yok oldu (RMS ~0.5 → ~0.005).
> Kullanım: `px4-mc_indi_tiltrotor slewbox 1.75`. Aktif değer log'dan
> `|du(3)| p99.5 / TS_BOX` ile geri okunur.
>
> **Adım 24 (2026-07-28) — "gölgeyi gerçek servoya sadık kıl" DENENDİ, GERİ
> ALINDI.** Sadakat açığının tamamı Coulomb sürtünme ölü bandıymış
> (friction/p_gain = **0.573°**); çevrimdışı doğrulamada 1. derece + ölü bant
> **3.5×/8.0×/139×** daha iyi, tam 2. derece model ise DAHA KÖTÜ (atalet
> birkaç ms'de oturuyor, 4 ms tick'in içinde). **Ama kapalı çevrimde
> kilitleniyor:** `du` slew kutusuyla 0.40° ile sınırlı, ölü banttan küçük →
> gölge ve komut birlikte donuyor (SITL: tilt'ler tüm uçuş donuk, yaw bandı
> 238°). Geri alındı. **Ders: açık çevrim replay (`servo_model.py`) kapalı
> çevrim geri besleme tuzağını gösteremez** — komut yolunun içindeki model
> değişikliklerini kapalı çevrimde doğrulayın.
>
> Ölçüm araçları (rebuild gerektirmez): `shadow_vs_real.py`,
> `gz_joint_csv.sh` (Adım 21'den beri rotor hızlarını da yazar),
> `logger_topics_shadow.txt`. Kullanım → `shadow_vs_real.py` docstring'i.
>
> **GUI'li gözlem** için `gz_follow.sh` (kamerayı araca kilitler) —
> zorunlu, çünkü yatay pozisyon döngüsü yok ve araç ~10 m/s sürükleniyor.

MATLAB kontrolcüsünün (`indi_attitude_controller.m` + LESO + WLS +
`altitude_loop.m`) PX4 C++ portu `~/PX4-Autopilot/src/modules/mc_indi_tiltrotor/`
altında; yeni `gz_tiltrotor_indi` airframe'i Model-3'ün (`tiltrotor_tailplane`)
Gazebo modelini yeniden kullanır. Tasarım kararları ve kapsam sınırları için
bkz. `~/.claude/plans/cached-dancing-puppy.md`.

## Başlatma

```bash
pkill -9 -f 'px4_sitl_default/bin/px4'; pkill -9 -f 'gz sim'; rm -f /tmp/px4-sock-0
cd ~/PX4-Autopilot/build/px4_sitl_default/src/modules/simulation/gz_bridge
PX4_SIM_MODEL=gz_tiltrotor_indi HEADLESS=1 ../../../../bin/px4 -d > /tmp/px4.log 2>&1 &
grep -a 'Ready for takeoff' /tmp/px4.log   # bekleyin
```

Kaynak değiştiyse önce derleyin: `cd ~/PX4-Autopilot && make px4_sitl_default`.

## Test sürücüsü

```bash
export PATH=~/PX4-Autopilot/build/px4_sitl_default/bin:$PATH
cd "tiltrotor_Matlab files/sitl"
python3 smoke_test.py     # M4 doğrulaması: arm + hover setpoint + EKF sağlık takibi
```

`indi_sitl_common.py` — `Px4Client` sınıfı `px4-mc_indi_tiltrotor test_sp`,
`px4-commander`, `px4-listener` client binary'lerini shell'leyerek sürer
(özel `tiltrotor_indi_setpoint` uORB topic'i için MAVLink köprüsü yok —
harici MAVLink istemcileri rastgele uORB topic'i yayınlayamaz; bu yüzden
aynı işlemin client'ları kullanılıyor, `px4-listener`'ın çalışma şekliyle
aynı).

## Bilinen davranış / tuzaklar

- **`COM_DISARM_PRFLT` (10 s):** arm edilip gerçek itki komutlanmadan
  10 saniye geçerse PX4 kendini disarm eder ("auto preflight disarming").
  Test script'leri arm sonrası setpoint'i hemen göndermeli. **2026-07-24'e
  kadar bu, her M5/M6 koşusunda deterministik biçimde tetikleniyordu** —
  gerçek neden setpoint zamanlaması değil, `mc_indi_tiltrotor`'ın
  `vehicle_thrust_setpoint`'i hiç yayınlamamasıydı: PX4'ün stok
  `MulticopterLandDetector`'ı "havada mı" kararını bu topic'ten veriyor,
  topic gelmeyince `landed=true` sabitleniyor ve gerçek Gazebo fiziğinden
  bağımsız olarak COM_DISARM_PRFLT tetikleniyordu. Düzeltildi (modül artık
  komut edilen ortalama itkiyi bu topic'e de yazıyor) ve doğrulandı — bkz.
  [RUNBOOK.md §0](RUNBOOK.md#0-ön-koşul-land-detector-düzeltmesi-derlenmiş-olmalı).
- **`estimator_status_flags` ~1 Hz'de yayınlanır** (sürekli akış değil, durum
  değişince/periyodik). Modüldeki EKF sağlık kapısı bunu 3 saniyelik bir
  tazelik penceresiyle kontrol eder — daha sıkı bir pencere (ilk denemede
  500 ms) `cs_tilt_align`/`cs_yaw_align` gerçekte sabit `True` iken kontrolcü
  çıkışının her iki adımda bir NaN/gerçek değer arasında "titremesine" yol
  açtı (bkz. modül yorumları).
- **`fs_bad_*` (füzyon hata) bitleri sağlıklı uçuşta bile anlık titreşebilir**
  — modülün sert (per-tick) EKF kapısı yalnızca `cs_tilt_align`/`cs_yaw_align`
  (yapışkan/kalıcı bayraklar) kullanır; `fs_bad_*` yalnızca uçuş-sonrası M7
  raporunda değerlendirilir.
- **`px4-listener <topic> -n N` (N>1) disarmed'ken takılabilir** — argümansız
  (`-n 1` veya hiç) çağırın.

## Bilinen açık sorun (M6, çözülmedi)

`run_transition_test.py` şu an WLS tahsisinde gerçek bir hata ortaya
çıkarıyor: `Fx_sp` 0→10N rampalanırken ileri hız pratikte sıfırda kalıyor
ve rotor tilt/itki dağılımı beklenen simetrik-yakın-sıfır-tilt hover
dengesine değil, asimetrik bir konfigürasyona yakınsıyor (sağ kanat rotoru
T0≈0N'a düşüyor, sol kanat tek başına ağırlığın çoğunu taşıyor, **kuyruk
rotoru ~33° tilt taşıyor** — halbuki `CA_SV_TL2_CT=0` mantığı gereği kuyruk
tilt'inin yaw'a katkısı olmaması bekleniyordu ve bu büyüklükte bir tilt hiç
beklenmiyor). Bu durum 14s'lik settle sırasında oluşuyor ve Fx rampası
boyunca değişmeden kalıyor.

**Zaten yapılan/doğrulanmış olan:** Gölge aktüatör durumunun arm anında
naif (eşit itki, sıfır tilt) yerine `hoverTrim()` (hover_trim.m portu) ile
tohumlanması, arm sonrası ~90° yaw sapmasının süresiz büyüyüp çökmeye yol
açmasını düzeltti — sistem artık ~10s'de <2° yaw hatasına yakınsıyor.
Bu düzeltme kalıcı (`TiltrotorIndiControl.hpp:hoverTrim()`,
`MulticopterIndiTiltrotor.cpp` seed bloğu).

**Sonraki adım (yapılmadı):** WLS iterasyonlarını (`wlsAllocate()` içindeki
6 big-M iterasyonu) adım adım loglayıp hangi kutu-kısıtın T0'ı sıfıra
ittiğini ve kuyruk tilt'inin neden büyüdüğünü izole etmek; MATLAB'ın kendi
`hover_trim(p)` çıktısıyla `effectivenessMatrix()`'in sayısal çıktısını
karşılaştırmak (G/nu0 matrisinde bir işaret/indeks hatası olabilir).

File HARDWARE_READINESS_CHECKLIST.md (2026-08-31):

# Donanım testi hazırlık kontrol listesi — `mc_indi_tiltrotor`

**Hazırlanma tarihi:** 2026-07-29 (Adım 28 sonrası; B5 Adım 31'de, B1 Adım
32-35'te güncellendi — son güncelleme 2026-08-03, **Adım 39: madde (S)
KAPATILDI** — `BRAKE → HANDOFF` eşiği ve fren marjı artık hız BÜYÜKLÜĞÜNÜ
değil, yasanın kontrol ettiği ekseni (işaretli gövde ileri hızı) okuyor;
B5 🔴 → 🟠. Madde (T) 🟠 açık ama artık enstrümanlı.)
**Kısa cevap: HAYIR, donanıma geçmeye hazır değil.** Durum 🔴 **NO-GO** —
B1/B2/B3/B4 hâlâ 🔴 ve **hiçbir şey gerçek donanımda uçmadı**.

SITL'de artık her kriter geçiyor (Adım 27-28: kilitlenme yok, yaw kararlı,
duruş 0.06 m, asimetri 1.02×). Ama **SITL'de geçmek, donanımda uçmaya hazır
olmak demek değil** — ve bu projenin kendi geçmişi tam olarak bunun kanıtı:
Adım 11, 12, 21 ve 27'nin dördü de *kontrolcü ile plant arasındaki arayüz*
hatalarıydı ve **saf MATLAB bunları yapısal olarak göremiyordu**. Donanımda
plant GERÇEK; yani bu sınıftaki her hata doğrudan uçuşta ortaya çıkar.

Aşağıdaki listede 🔴 = uçuştan önce **zorunlu**, 🟠 = kısmen çözüldü ama
yalnızca simülasyonda doğrulandı, 🟡 = ilk uçuştan önce güçlü tavsiye,
🟢 = hazır/kapalı.

---

## 0-Z. KART TAKILDIĞINDA YAPILACAKLAR (2026-08-31, adım 141)

Kart olmadan yapılabilecek her şey bitti (bkz. §0-A). Bu bölüm, **Cube Orange
elde olduğu anda** sırayla yapılacak işlerin listesi. Hiçbiri tahminle
yazılamaz — hepsi ölçüm gerektirir.

### K1 — Firmware yükle ve airframe'i seç
```
~/PX4-Autopilot/build/cubepilot_cubeorange_default/cubepilot_cubeorange_default.px4
param set SYS_AUTOSTART 14002      # 14002_tiltrotor_indi
param set SYS_HITL 1               # HITL modu
```
Firmware **güncel** (2026-08-31 derlemesi, flash %84,50, RAM %8,21). Airframe
ve `.post` ROMFS'te doğrulandı.

### K2 — ⚠ ÇIKIŞ KABLOLAMASINI DOĞRULA (en kritik madde)

`14002_tiltrotor_indi` şu dağılımı **varsayıyor**; modül hangi pinin ne
sürdüğünü bilmez, eşlemeyi bu parametreler yapar:

| Cube Orange pini | bağlı olmalı | fonksiyon |
|---|---|---|
| MAIN 1 | sağ kanat rotoru ESC | Motor1 (101) |
| MAIN 2 | sol kanat rotoru ESC | Motor2 (102) |
| MAIN 3 | kuyruk rotoru ESC | Motor3 (103) |
| MAIN 4 | sol elevon | Servo1 (201) |
| MAIN 5 | sağ elevon | Servo2 (202) |
| MAIN 6 | sol elevator | Servo3 (203) |
| MAIN 7 | sağ elevator | Servo4 (204) |
| MAIN 8 | rudder | Servo5 (205) |
| **AUX 1** | **sol kanat tilt servosu** | Servo6 (206) |
| **AUX 2** | **sağ kanat tilt servosu** | Servo7 (207) |
| **AUX 3** | **kuyruk tilt servosu** | Servo8 (208) |

**İki sessiz ve pahalı hata sınıfı:**
1. **Sıra karışması** (sağ/sol rotor ters): araç ters yöne roll yapar.
   Kontrolcü doğru komut verir, tel yanlış motora gider.
2. **Tilt servoları MAIN'e takılırsa:** `PWM_AUX_MINA1/MAXA1 = 0..90`
   ölçeklemesi uygulanmaz, sürücü varsayılan ±57,3°'ye düşer ve tilt komutu
   YANLIŞ ÖLÇEKLENİR — 45° komutu ~28° gerçek açı verir.

Doğrulama (pervanesiz!):
```
px4-actuator_test set -f 101 -v 0.1    # MAIN1 -> sag kanat rotoru
px4-actuator_test set -f 206 -v 0.5    # AUX1  -> sol kanat tilt ~45 deg
```

### K3 — HITL köprüsünün MAVLink yarısı
`hitl/gz_hil_bridge.py`. gz tarafı **ölçüldü** (IMU 250 Hz, 3/3 abone);
MAVLink tarafı `[YAZILDI]` ama kartta hiç koşmadı.
```
./hitl/run_hitl_check.sh                                    # once gz tarafi
python3 hitl/gz_hil_bridge.py --dev /dev/ttyACM0 --baud 921600
```
⚠ **İlk kontrol çerçeve dönüşümü:** gz FLU → PX4 FRD `(x, −y, −z)`. Bu
projenin en pahalı iki hatası (Adım 12 `ROTOR_KM`, engelleyici B4 `ROTOR_PY`)
tam olarak bu dönüşümün atlanmasından doğdu. Kart ters işaretli ivme görürse
derhal devrilir. Doğrulama: araç yatay dururken `az ≈ +9.81` (FRD'de aşağı
pozitif) okunmalı.

### K4 — `pump_actuators()` ölçeğini ÖLÇ
Yayın tarafı hazır ve ölçüldü; eksik olan **ölçek**. PX4 normalize (0..1)
gönderir, gz motor modeli rad/s bekler (`SIM_GZ_EC_MIN/MAX = 10/1500`).
Bu dönüşüm `thrustToNormalized()`'in tersidir ve yanlış ölçek = yanlış itki —
Adım 11'in tam olarak ödediği bedel.

**İlk iş tahmin etmek değil, ölçmek:** karttan gelen `HIL_ACTUATOR_CONTROLS`
mesajının `controls[0..2]` değerlerini logla, hover komutunun hangi sayıya
karşılık geldiğini gör, sonra eşlemeyi yaz.

### K5 — Manyetometre yolunu çöz
gz'de manyetometre konusu **YOK**. SITL'de onu Gazebo değil PX4'ün kendi
`sensor_mag_sim` modülü üretiyor (`SENS_EN_MAGSIM 1`). Gerçek kartta o modül
çalışmayacak — kart gerçek bir manyetometre taşıyor ama o, SITL'in dünyasından
habersiz ve **yanlış heading** verir.

Üç seçenek, hiçbiri ölçülmedi:
(a) gz dünyasına bir magnetometer sensörü eklemek ve köprüden `HIL_SENSOR`'un
    mag bitleriyle göndermek (en temiz, `BIT_MAG` zaten kodda);
(b) kartın gerçek manyetometresini kullanıp SITL'i onun heading'ine hizalamak;
(c) `HIL_STATE_QUATERNION` ile tutumu doğrudan enjekte etmek (EKF'i baypas
    eder, yani HITL'in test ettiği şeyin bir kısmını kaybeder).

### K6 — B3: itki eşlemesini gerçek motor/ESC eğrisinden türet
`thrustToNormalized()` hâlâ **Gazebo sabitlerine** kalibre: `ROTOR_KF = 2e-5`,
`ROTOR_WMAX = 1500`, `ROTOR_WMIN = 10`. Aynı sayıları gerçek donanıma taşımak
yeni bir itki eşleme hatası yaratır (Adım 11).

Airframe dosyasında `PWM_MAIN_MIN/MAX` ve ESC kalibrasyonu **bilerek yok** —
ikisi de bu ölçüme bağlı. Statik itki tezgâhı gerekir: her rotor için
komut → devir → itki eğrisi.

### K7 — B2: fiziksel sabitleri ÖLÇ
Kütle, atalet, rotor konumları, `km` — hepsi bugün SDF'ten geliyor, **hiçbiri
ölçülmedi**. Ağırlık merkezi de: `check_mass_balance.py` bu oturumun geometri
değişikliklerinin CG'yi **16 mm geriye** kaydırdığını hesapladı, ama gerçek CG
ancak tartılarak bulunur (statik pay hesabı %40,7 → %34,2; tipik hedef %5-15,
yani hâlâ fazlasıyla kararlı tarafta).

### K8 — B4: `ROTOR_PY` işaretini fiziksel olarak doğrula
Simülasyon tarafı çözüldü, fiziksel doğrulama duruyor. Araç sabitken tek bir
kanat rotorunu düşük gazda çalıştırıp roll momentinin yönünü gözle.

### K9 — H7: kartta tick jitter ölçümü
Döngü 400 Hz (2,5 ms bütçe). GUI koşumları bu gövdenin zamanlama sarsıntısına
duyarlı olduğunu gösterdi (aynı ikili: GUI'de 112 BIG_M, headless 0).
`perf` çıktısı ve `_loop_perf` sayaçları ile ölç.

### K10 — H8: RC yolu (`RC_CHANNELS_OVERRIDE`)
Adım 40'ta "sınanmadı" diye kayıtlı; tüm pilot testleri MAVLink
`MANUAL_CONTROL` üzerinden yapıldı. VTOL anahtarı → `bt_enable` yolu bu
kanaldan geliyor.

---

## 0-A. HITL KAPISI (2026-08-29, Adım 120-121 — bu bölüm YENİ)

Bu listenin geri kalanı **serbest uçuşu** hedefliyor ve 3 Ağustos'ta (Adım 39)
dondu; çalışma logu ise Adım 121'de. HITL ayrı ve daha yakın bir kapı: plant
hâlâ Gazebo olduğu için **B2/B3/B4 HITL'i bloklamaz** (hepsi plant gerçek
olunca ısırır). HITL'e özgü durum:

| # | madde | durum |
|---|---|---|
| H1 | Modül gerçek kartta derleniyor | 🟢 **KAPANDI** (Adım 120) — `cubepilot_cubeorange`, `CONFIG_MODULES_MC_INDI_TILTROTOR=y` eklendi |
| H2 | `wlsAllocate` yığın taşması | 🟢 **KAPANDI** (Adım 120) — 2184 B > 2048 B sınırı; `WlsScratch` ile modül üyesine taşındı |
| H3 | Flash bütçesi | 🟢 **KAPANDI** (Adım 121-122) — %97,98 → **%84,03**; 13 modül budandı, her turda SITL'de uçurularak doğrulandı. `MC_POS_CONTROL` bilerek KALDI (`mc_hover_thrust_estimator` çalışıyor ve `MPC_THR_HOVER`'ı okuyor) |
| H4 | RAM bütçesi | 🟢 %8,21 (43 KB / 512 KB) — sorun değil |
| H5 | Gerçek kart airframe dosyası + param seti | 🟢 **KAPANDI** (Adım 122) — `14002_tiltrotor_indi` + `.post`, `CMakeLists.txt`'e koşulsuz kaydedildi. Çıkış atamaları SITL sırasıyla birebir; **kablolamaya göre doğrulanmalı** |
| H6 | `SYS_HITL` + sensör köprüsü yapılandırması | 🟡 **KURULDU, KARTTA KOŞMADI** (Adım 149) — `14003_tiltrotor_indi_hitl` airframe'i eklendi ve ROMFS'e girdiği doğrulandı; 14002'yi kopyalamaz, **kaynak gösterir**. `SYS_HITL 1` + `HIL_ACT_FUNC1..11` (14002'nin çıkış sırasıyla birebir) + emniyet devre kesiciler. Kaynaktan okundu: HIL'i açan şey parametre değil `commander -h` (`Commander.cpp:2669`); `SYS_HITL>0` rcS'in o dalını tetikler. ⚠ `set_hil_enabled` **datarate > 5000** ister — USB'de 100000, ama 57600 baud UART'ta 2880 olur ve HIL **sessizce açılmaz**. Köprüye kanal eşlemesi (`HIL_CHANNELS`) ve ölçek kaydedici (`log_actuator_scale`) eklendi; `pump_actuators()` ölçek ölçülene kadar hâlâ açık (K4). |
| H7 | Kartta CPU/tick jitter ölçümü | 🔴 **AÇIK** — döngü 400 Hz (2,5 ms). GUI koşumları bu gövdenin zamanlama sarsıntısına duyarlı olduğunu gösterdi (Adım 121 öncesi ölçüm: aynı ikili, GUI'de 112 BIG_M / headless 0) |
| H8 | RC vericisi ↔ kart (`RC_CHANNELS_OVERRIDE` yolu) | 🔴 **AÇIK** — Adım 40'ta "sınanmadı" diye kayıtlı; tüm pilot testleri MAVLink `MANUAL_CONTROL` üzerinden |
| B0 | Kartta iniş/görev yolu | 🟢 **KAPANDI** (Adım 154) — **tam görev artık modülde**. `missionSequencer()` + `MissionState` (CLIMB→HOVER→FWD→CRUISE→FW→FW_CRUISE→BACK→SETTLE→LAND→DONE) tek bir `mission_enable` bayrağıyla sürülür; ft/bt/fw/land bayraklarını ve z_sp'yi **dizici üretir**. Geçişler olay tabanlı (ft_state==CRUISE, fw_state==ACTIVE, bt_state==HANDOFF, land_state==TOUCHDOWN); yalnızca seyir süreleri zamanlı. Zaman aşımında **geri geçişe düşer** — her arızada araç hover'a döner ve iner. SITL'de doğrulandı: 10 evrenin 10'u, 157 s, tırmanışta v_h 0,28 m/s, sabit kanatta tilt 90°/14,4 m/s, temas agl 1,21 m. Test: `sitl/run_autonomous_mission.py` (yalnızca bayrağı kaldırır ve izler). Modül **DISARM ETMEZ** — DONE yalnızca bildirir. ⚠ Kartta bayrağı kaldırmak hâlâ RC yoluna bağlı (H8). |
| B1 | Pilot girişi + kademeli failsafe | 🔴 açık — HITL'in varlık sebebi; alçak irtifada hızlı link kaybı hâlâ 100+ m sürüklenmeyle bitiyor |

**ESP32 (companion) — ölçülmüş değerlendirme:** yetersizlik CPU'da değil
**flash'ta**. ESP32 iç döngüyü alamaz (400 Hz, 2,5 ms; UART/MAVLink üzerinden
taşınamaz), ama sürü kararı / görüntü-ses işleme / faydalı yük mantığını
üstlenirse karşılık gelen PX4 modülleri karttan düşürülebilir — katkısı
**flash boşaltmak** olur. Adım 121'den sonra bu baskı zaten büyük ölçüde kalktı.

---

## 0. Beş engelleyici (bunlar bitmeden hiçbir güçlü test yapılmamalı)

### 🔴 B1 — Pilot girişi ve failsafe: KOD YAZILDI, ölçüldü, kapsamı DARALTILDI

*(Adım 32-33 kodu yazdı — 2026-07-29; Adım 34 onu ilk kez ÖLÇTÜ ve seviye 3'ün
çalışmadığını buldu; Adım 35 seviye 3'ü ölçüp KALDIRDI — 2026-07-30.)*

**Bugünkü özet:** kademeli failsafe artık yalnızca **dış döngüler** hakkında bir
sav taşıyor (NO_POS ölçülerek doğrulandı, NO_ALT hâlâ tetiklenemedi). Duruş
kestirimi sert ön koşul oldu. **Pilot yolu 2026-08-03'te (Adım 40) İLK KEZ
ÇALIŞTIRILDI** — yedi dalın altısı ilk denemede doğru işledi, ama yedincisi
(link kaybı) savını tutmuyor: **madde (U), aşağıda.** B1 **hâlâ 🔴**.

> ### ✅ Adım 40 (2026-08-03) — pilot yolu çalıştırıldı, ve önce dört gizli taşma düzeltildi
>
> **Ulaşılabilirlik önce UÇMADAN ölçüldü** (`sitl/probe_pilot_link.py`). Modülün
> pilot dalı iki koşula bağlı ve asıl risk bizim gönderdiğimizde değil,
> **commander'ın verdiği** `flag_control_manual_enabled`'daydı: akış yokken
> `False`, MAVLink `MANUAL_CONTROL` akışı başlayınca **`True`** (valid=True,
> source=3, nav_state 4→2). Param değişmedi — `COM_RC_IN_MODE` varsayılanı 3
> zaten joystick kabul ediyor. `manual_control_switches` (VTOL anahtarı →
> `bt_enable`) yalnızca `RC_CHANNELS_OVERRIDE` ile geliyor; **o yol hâlâ
> sınanmadı.**
>
> **🔴 Dört gizli taşma.** Adım 32'nin bulduğu `(now - topic.timestamp) < T`
> deseni (iki `uint64`, `now` = gyro ÖRNEK zamanı) **dört yerde daha duruyordu**;
> Adım 32/33 düzeltmeyi yalnızca ısırdığı iki yere uygulamış. Ölçüldü:
> `estimator_status_flags` bu uçuşlarda hiç taşmıyor (39217 tick'te 0), ama
> `vehicle_attitude` **düzeltme olmasaydı %0.03 taşacaktı** — form hatalı, SITL
> maskeliyor (gz gyro'sunun publish−sample farkı ~0 µs, çünkü lockstep; **gerçek
> sensör hattında o gecikme gerçektir**). Dördü de toplama formuna çevrildi. En
> kritik ikisi: `tilt_aligned` (Adım 35'ten beri `att_ok` false ⇒ çıkış kesilir,
> yani taşma gerçek duruş kaybından ayırt edilemez — **madde (T)'nin imzası;
> (T)'yi kapatmaz ama Adım 38'in düşünmediği üçüncü aday mekanizmayı eler**) ve
> pilot tazeliği (orada topic gerçek zamanla damgalanıyor, yani "topic now'dan
> yeni" normal durum — taşan formda bir çubuk girdisi sessizce yok sayılırdı).
>
> **Uçuş sonucu** (`sitl/run_pilot_input_test.py`, iki bağımsız GUI'li uçuş):
> devralma tam bir kez ve basamaksız ✅; çubuklar ortada → `pos_hold`
> kendiliğinden (%28-30) ✅; **pilot sahipken max |roll| 8.2-8.3°, |pitch|
> 8.4-8.5°** = 0.5 çubuk × `MAN_TILT_MAX` 15° komutunun tam karşılığı ✅; yaw
> çubuğu 120-164° ✅; throttle 13.7-13.9 m ✅; havada NaN 0, BIG_M 0,
> `attitude LOST` 0 ✅. Zorunlu `sitl-lockup-check` geçti (%0.00/0, yaw −8.93°,
> irtifa RMS 0.089 m).
>
> ### 🔴 madde (U) — link kaybı dalı TUTAMADIĞI bir şeyi iddia ediyor
>
> Dal tetikleniyor ve `pilot input LOST -- holding position and descending`
> yazıyor. **Ölçüm: alçalma boyunca `pos_hold_active` hiç 1 olmuyor ve araç
> 4.8-6.1 m/s ile uçarak iniyor, ~100 m ileride yere değiyor** (iki uçuşta da,
> ortalama 5.43 / 5.46 m/s). Zincir tamamen bilinen parçalardan: çubuk
> evrelerinde madde (N)'nin yapısal ileri ivmesi aracı 9.3 m/s'ye çıkarıyor →
> `pos_hold REFUSED: 9.3 m/s > 3.0` → link kaybı dalı `req_pos_hold = true`
> diyor ama bu yalnızca bir **İSTEK**, `POS_ENGAGE_V_MAX` reddetmeye devam
> ediyor → ve dal, aracı yavaşlatabilecek tek mekanizmayı **açıkça kapatıyor**:
> `req_bt = false`. Kontrol listesi bunu Adım 34(d)'de zaten yazmıştı
> (*"Station keeping must be handed to `bt_enable` on recovery — not wired"*),
> ama orada kurtarma yolundaydı; **burada müdahale edecek kimsenin olmadığı
> durumda.** Madde (S) ile aynı yapısal desen: alıcının reddedebildiği bir
> istek, ve reddedilirse yedeği olmayan bir tasarım.
>
> **✅ ADIM 41'DE DÜZELTİLDİ VE DOĞRULANDI (2026-08-03).** `req_bt = false` yerine
> **`req_bt = !_pos_hold_active && (v_h > POS_ENGAGE_V_MAX || _bt_state != IDLE)`**
> — yani hold kabul edemeyecek kadar hızlıysa araç, işi tam olarak "seyirden
> hover'a" olan makineye devredilir. `_bt_state != IDLE` **mandalı** şart:
> yoksa hız eşiğin altına düştüğü anda `req_bt` düşer, makine IDLE'a sıfırlanır,
> tavan bırakılır ve bir tick sonra yeniden başlar — manevra bitmek yerine
> sürekli baştan başlardı. Bırakma koşulu `_pos_hold_active`, çünkü manevranın
> varlık sebebi zaten odur. Alçalma bunun altında bağımsız olarak sürer: geri
> dönecek bir pilot yok, iniş yavaşlamayı BEKLEMEMELİ.
>
> **Ölçüm — düzeltme öncesi/sonrası, aynı test:**
>
> | | link kaybı irtifası | yatay yol (kayıptan temasa) | temas v_h | alçalırken ort. v_h |
> |---|---|---|---|---|
> | öncesi | 7-13 m | **104-110 m** | **4.96-5.39 m/s** | 5.43-5.46 |
> | sonrası | 17.8 m | **13 m** | **0.16 m/s** | **1.33** |
>
> px4 log'unda dizinin tamamı görünüyor: `pilot input LOST at 5.0 m/s -- too fast
> ... handing over to the back-transition` → `state 0 -> 1 -> 2 -> 3` →
> `pos_hold: holding` → `state 3 -> 0`. Yedi ölçütün yedisi de geçti.
>
> **ÖNEMLİ SINIR — düşük irtifada bu düzeltme DEVREYE GİRMEZ ve girmemeli.**
> İlk denemede link kaybı 7.2 m AGL'de oluştu ve log `back-transition REFUSED:
> 7.2 m AGL < 15.0 m minimum` yazdı: 30-40 s'lik bir manevra için yer yok, doğru
> cevap zaten "hemen in". Yani madde (U) **irtifası olan** link kaybı için
> kapandı; **alçak irtifada hızlı link kaybı hâlâ 100+ m sürüklenmeyle biter** ve
> bunun çözümü geri geçiş değil (yatay eksene doğrudan bir fren gerekir).
> Test senaryosu bu yüzden tırmanışı 13 m'den ~30 m'ye çıkardı — düzeltmenin
> hedeflediği rejimi kurmayan bir koşu onu sınamaz (Adım 39'un dersi).

> ### 🔴 madde (V) — İLERİ GEÇİŞ bir kontrol yasası değil; otonom görev bu yüzden eksik
>
> *(2026-08-03, Adım 41'de "pilot komut edemiyor" olarak açıldı; **aynı gün
> gereksinim netleşince 🟠 → 🔴 yükseltildi ve yeniden çerçevelendi.** Hedef tam
> otonom görevdir — kalkış multikopter, seyir sabit kanat/tilt motor, iniş
> multikopter — yani sorun "pilot süremiyor" değil, **hiçbir şey otonom
> süremiyor**: ileri geçişin tek yolu bir hata ayıklama konsoludur.)*
>
> **Eksikti üç parça; biri ADIM 42'DE KAPANDI:**
> 1. ~~İleri geçiş yasası yok~~ → **✅ YAZILDI VE UÇTU (Adım 42, 2026-08-03).**
>    `forwardtrans_loop.m` / `forwardTransition()`, üç durum
>    (IDLE→RAMP→CRUISE), `ft_enable` bayrağı. **Tilt komut ETMEZ** — `fx`'i
>    rampalar, tilti WLS seçer; gerekçe ölçüm: ileri yönde tahsisatın kendi
>    tercihi zaten doğru yöne bakıyor (geri yönde bakmıyordu, orada KUTU KISITI
>    gerekmişti). Pitch her zaman 0 (Adım 29), `pos_hold` bırakılır, iptal
>    **geri geçişi ister** (`fx = 0` işe yaramaz — Adım 30). İki emniyet farklı
>    cinsten: irtifa bandı 5 m (aero-bağımlı) + süre 30 s (aero-bağımsız).
>    **Doğrulama: iki bağımsız otonom görev uçuşu** — kalkış → ileri geçiş
>    (14.4 s) → **tilt 44.1° / 15.2 m/s seyir** → geri geçiş → hover → iniş,
>    elle hiçbir komut yok. İrtifa sapması 0.58-0.80 m, doyum %0.00, BIG_M 0,
>    NaN 0, iptal 0. Mantık testi 16/16, MATLAB regresyonu nötr,
>    `sitl-lockup-check` geçti. Test: `sitl/run_mission_test.py`.
> 2. **Seyirde enerji yönetimi yok** (TECS benzeri bir yasa) — 🔴 AÇIK. Adım 29
>    ölçtü: ~5-6 m/s üstünde burun yukarı bir *tırmanma* komutudur ve irtifa
>    döngüsü kanat taşımasına karşı koyamaz. Şu an seyirde `fx` sabit tutuluyor.
> 3. **Görev dizicisi yok** — 🔴 AÇIK. Evreleri hâlâ dışarıdan gelen iki bayrak
>    zincirliyor. PX4'ün `navigator`/`flight_mode_manager`'ı bu airframe'de
>    kasıtlı durdurulmuş, yani diziyi modül yürütmeli.
>
> **Madde (V) bu yüzden 🔴 kalıyor ama kapsamı daraldı:** eksik olan artık
> geçiş yeteneği değil, onu bir GÖREVE bağlayan katman.
>
> ### 🟠 Adım 48 (2026-08-04) — ileri geçiş İPTAL ETMİYOR; ve iptalin kaçış yolunun sıfır marjlı olduğu bulundu
>
> **GEREKSİNİM:** görev profili tek parçadır ve ileri geçiş kendini kesmez
> (`FT_ALLOW_ABORT = false`). İki emniyet dedektörü **silinmedi** — çalışıyor ve
> `warn_code` ile loglanıyor; yalnızca eylemleri kalktı. `true` yapmak eski
> davranışı birebir geri getirir ve iki mod da test ediliyor (21 denetim; uyarı
> iptalin tetikleneceği **tam aynı anda** çıkıyor, t = 4.56 s).
>
> **🔴 DONANIM İÇİN ÖNEMLİ BULGU (kod okumasıyla, uçuşla DEĞİL):** iptalin
> garantili bir kaçış yolu yoktu. İptal = geri geçişi İSTEMEK (Adım 30 ölçtü:
> `fx_sp = 0` tiltleri geri çekmiyor, araç yavaşlamıyor), ve geri geçiş
> `BT_MIN_ALT` altında başlamayı reddediyor. Sabitler sıfır marj bırakıyordu:
>
> ```
> FT_MIN_ALT (20 m)  −  FT_ALT_BAND (5 m)  =  15 m  =  BT_MIN_ALT
> ```
>
> Yani **alçalarak** iptal eden bir geçiş, tam olarak kaçışının reddedildiği
> irtifada iptal ediyordu — o köşede iptal etmek etmemekten kötüydü (seyir
> hızında, tiltler önde, kimsenin sahiplenmediği araç). Madde (U) ve (R) ile
> aynı kalıp. **İptal ileride geri getirilirse ÖNCE bu marj kapatılmalıdır.**
>
> Doğrulama: PX4 derlemesi temiz, tam otonom görev **6/6 GEÇTİ** (FT
> RAMP→CRUISE tilt 42.5°, BT RETRACT→BRAKE→HANDOFF, iptal ×0, NaN 0,
> doygunluk %0.00).
>
> ### 🔴 Adım 46 (2026-08-03) — 3. deneme MATLAB'da ÇALIŞIYOR, ama PX4'e GİTMEDİ; ve TECS bir ENGELLEYİCİYE dönüştü
>
> Kontrol yüzeyleri artık beş bağımsız aktüatör değil **üç sanal aktüatör**
> (aileron = antisimetrik elevon → Fz ve pitch tam cancel; elevator = simetrik
> servo_2/3, 0.70 m dürüst kuyruk kolu; rudder). Simetrik elevon (flap) bilerek
> aktüatör değil — ağırlık penceresi hesabı onun için **boş** çıkıyor
> (131.2 < wu < 43.5, ters), yani Adım 45/deneme 1 hiçbir ağırlıkla
> kurtarılamazdı. MATLAB'da fx = 10 N / 70 s: tilt **52.1° → 70.6°**, kanat yük
> payı **%98.9 → %106.4**, toplam rotor itkisi **24.0 → 16.1 N**, max |ω|
> 0.021 → 0.013 (iyileşti).
>
> **SITL'e gönderilmedi, çünkü MATLAB kapısı temiz değil:**
> 1. 🔴 **Aileron, elevator olmadan açıkken ıraksıyor** (fx = 10 ve 12'de
>    bağımsız olarak tekrarlandı). Yüzeyler ancak BİRLİKTE devreye alınabilir.
> 2. 🔴 **fx ≥ 12 N'de rejim yüzeyler KAPALIYKEN BİLE marjinal**: doygunluk
>    %13.5-16.1, kanat tilt'i 90° mekanik durakta çakılı. Aracı yavaşlatan şey
>    bir yasa değil o durak; yüzeyler bu kazara korumayı kaldırıyor.
>
> **(2)'nin sonucu: seyirde enerji yönetimi (TECS) artık "eksik" değil,
> yüzeylerin ÖN KOŞULU.** Sıradaki iş yüzey ayarı değil, o katman.
>
> **Aynı adımda MATLAB plant'inde iki gerçek kusur bulundu ve düzeltildi:**
> kanadın taşıma **işareti tersti** (15 m/s'de burun yukarı 43-67 N *aşağı*) ve
> sürükleme ~7 kat fazlaydı. Bu, hem donanım riski açısından hem de metodolojik
> olarak önemli: **bu plantla yapılmış her MATLAB seyir/geçiş değerlendirmesi,
> Adım 46 öncesinde ters işaretli bir kanatla yapılmıştı.** Yeni plant
> (`aero_panels.m`) SITL'de ölçülen kanat yük payını (%41-50) bağımsız olarak
> yeniden üretiyor.
>
> **Aşağıdaki bölüm maddenin ilk (pilot merkezli) yazımıdır — ölçümü geçerli,
> çerçevesi güncellendi.**
>
> ### 🟠 madde (V) ilk yazımı — pilot ILERI geçişi hiç komut edemiyor (2026-08-03, Adım 41)
>
> GUI'li bir izleme sırasında kullanıcı sordu: *"tilti hiç görmedim, drone
> konseptiyle mi uçuyor?"* — ve haklıydı. Ölçüldü: pilot uçuşlarında kanat tilti
> havada yalnızca **3.7-15.1°** arasında oynuyor (yaw triminin δ0'ı tuttuğu
> aralık, madde (P)); araç **saf multikopter** olarak uçuyor.
>
> Sebep kodda tek satır: pilot dalı `fx_sp = 0.0f` **sabitliyor**. Çubuklar
> yalnızca duruş (≤ `MAN_TILT_MAX` = 15°) ve tırmanma hızı komut ediyor. Tek
> geçiş kontrolü VTOL anahtarı → `req_bt`, o da **geri** geçiş. Yani
> **pilot, hiç başlatamayacağı bir geçişi bitirebiliyor.** Seyre çıkmanın tek
> yolu tezgâh komutu `test_sp`'nin `fx` argümanı — yani bir hata ayıklama
> konsolu.
>
> Koddaki yorum *"gives the pilot both halves that blocker B5 called out as
> missing: they can START the manoeuvre and they can CANCEL it"* diyor; bu doğru
> ama **geri geçişin iki yarısı** için — uçuşun iki YÖNÜ için değil. Sav ile
> kapsamın karıştığı bir yer daha (Adım 35'in dersi).
>
> **Donanım açısından:** bir pilot bu araçla seyir uçuşu yapamaz, yani B5'in
> çözdüğü yetenek pilotun erişemediği bir yetenektir. Düzeltme yönü açık (bir
> çubuk/anahtar → `fx_sp` ya da bir ileri-geçiş isteği) ama **tasarım kararı
> gerektiriyor**: `fx_sp`'yi doğrudan pilota vermek, madde (N)'nin yapısal ileri
> ivmesiyle birleşince `pos_hold`'un reddedeceği hızlara çıkmanın en kısa yolu —
> yani madde (U)'nun tetikleyicisi. Ölçülmeden uygulanmamalı.

**Başlangıç durumu (Adım 31 sonu).** Modülde `manual_control_setpoint`,
`rc_channels`, failsafe, geofence, kill-switch **hiçbiri yoktu**. Yalnızca
`vehicle_control_mode.flag_armed` okunuyordu; tek setpoint kaynağı `test_sp`
konsol komutuydu. Yani araç havadayken müdahale yolu yoktu ve her bozulmuş
girdiye tek cevap `publishDisarmed()` — havada **motorları kesmek** — idi.

**Adım 32-33'te yazılanlar.** Dört seviyeli kademeli failsafe (`FsLevel`:
NONE / NO_POS / NO_ALT / RATE_ONLY — her biri yalnızca girdisi kaybolan
döngüyü kapatır; **RATE_ONLY adım 35'te kaldırıldı, aşağıya bakın**),
`manual_control_setpoint` üzerinden pilot girişi (açı
komutu roll/pitch, tazyikli yaw hız komutu + leash, throttle → tırmanma
hızı, çubuklar ortada → `pos_hold`), VTOL geçiş anahtarından `bt_enable`,
link kaybında pozisyon tut + alçal, ve `tiltrotor_indi_status.failsafe_level`
telemetrisi. Tasarımın dayanağı yapısal: **INDI hız döngüsü yalnızca ω ve
ω̇ istiyor**, ikisi de `vehicle_angular_velocity`'den geliyor — yani Run()
çalışıyorsa iç döngünün ihtiyacı tanım gereği mevcut.

Aynı oturumda **gerçek bir hata da bulundu ve düzeltildi**: eski tazelik
testi `(now - att.timestamp) < 50_ms` iki `uint64` üzerinde işaretsiz taşma
yapıyordu (`vehicle_attitude` bu tick'in gyro örneğinden ~4 ms İLERİDE
yayınlanıyor, çıkarma ~1.8e19'a sarıyor) → uçuş başına **7-13 kez havada
tüm motorlara NaN**. Görünmezdi çünkü hiçbir şey loglamıyordu.

**Adım 34'ün ölçümü (`sitl/run_failsafe_test.py`, seviye başına bir uçuş).**
Enjeksiyon, seviyeyi zorlayan bir kanca yerine kestirimi gerçekten alarak
yapıldı (kod her döngüde o döngünün KENDİ girdisine bakıyor, `_fs_level`
yalnızca en-kötü özeti — seviyeyi zorlamak dal gövdelerini çalıştırmazdı):

| Seviye | Enjeksiyon | Sonuç |
|---|---|---|
| 1 NO_POS | `EKF2_GPS_CTRL = 2` | ✅ **GEÇTİ.** 5 s sonra fs=1, motorlar kesilmedi (%0.0 NaN), **irtifa korundu**, açısal hız baseline'ın altında (0.081 vs 0.131), 0 BIG_M, geri alındığında ~3 s'de temizlendi |
| 2 NO_ALT | baro + GPS yükseklik kapalı | ⚠️ **TETİKLENEMEDİ** (iki farklı denemede) |
| 3 RATE_ONLY | `ekf2 stop` | ❌ **ARAÇ DÜŞTÜ** — aşağıya bakın. **Adım 35'te bu seviye KALDIRILDI** |

**❌ Seviye 3, kademeli tasarımın var olma sebebi olan seviye, ÇALIŞMIYOR.**
Modül doğru davrandı ve `failsafe 3 (att=0[cp=0 fresh=0 tilt=0] alt=0 xy=0)
-- degrading, NOT cutting` yazdı. **0.05 s sonra** `actuator_armed.lockdown`
true oldu, `terminationCommanded()` ona NaN'la cevap verdi ve araç 35 m'den
**serbest düştü** (gz yer gerçeği: 34.84 m → 0.10 m, ~2.7 s = tam serbest
düşüş). Yani RATE_ONLY tek bir 4 ms tick'ten uzun hiç çalışmadı.

Sebep, koddaki bir varsayımın ölçümle çürütülmesi. `terminationCommanded()`
yorumu "iki nedeni de *komut edilmiş*, çıkarsanmış değil" diyor; **ikisi de
yanlış**:

```
Commander.cpp:1881          armed.lockdown = (nav_state == NAVIGATION_STATE_TERMINATION)
                                             || HIL || throw_launch
ModeUtil/control_mode.cpp:119  flag_control_termination_enabled = true
                                             <- yine yalnızca nav_state == TERMINATION
```

Commander o duruma **otomatik** giriyor: attitude geçersizken
`FailsafeBase::modeCanRun()` başarısız, yedek mod yok (bu airframe'in `.post`
betiği `flight_mode_manager` ve `mc_pos_control`'ü durduruyor), failsafe
`Action::Terminate`'e yükseliyor. Gerçekten insan kararı olan tek şey
`manual_lockdown` (kill switch). Ayrıca ölçüldü: `gz_bridge`
`actuator_armed`'a hiç bakmıyor — aracı düşüren NaN'ı **modülün kendisi**
yazdı, yani karar bizim tarafta.

**✅ KARAR VERİLDİ VE UYGULANDI — ADIM 35 (2026-07-30): RATE_ONLY KALDIRILDI.**

Adım 34 üç seçenek bırakmıştı (1: commander'ın otomatik sonlandırmasını
görmezden gel; 2: RATE_ONLY'yi dürüstçe geri çek; 3: commander'ı hiç
TERMINATION'a sokma). Karar **ölçümle** verildi, tercihle değil.

**Önce ölçüm — `run_rate_only_test.m`.** Sav bir kontrol-yasası savı olduğu
için doğru yer MATLAB'dı: orada commander yok, yani seviye ilk kez 50 ms'den
uzun çalışabildi. PX4 dallarının birebir karşılığı kuruldu (`att_sp = att`
⇔ `omega_sp = 0`; irtifa döngüsü kapalı, `Fz = -m·g·0.97` açık çevrim;
`fx_sp = 0`), kontrolcüde hiçbir değişiklik gerekmedi. Üç senaryo, çünkü
savın kendisi ("hangi yatışta ise onu korur") başlangıç koşuluna bağlı:

| senaryo | >30° yatış | max \|roll\| | yaw savrulma | çarpma vz |
|---|---|---|---|---|
| 1) temiz hover | 45.3 s | 179.6° | +287° | 11.7 m/s |
| 2) gust + roll bozucusu | 12.2 s | 154.2° | +208° | 23.7 m/s |
| 3) 10° yatık girildi | 1.7 s | 122.1° | +391° | 19.6 m/s |

(35 m'den serbest düşüş referansı: 2.67 s, 26.2 m/s. Süreler bozulma anından
itibaren.) **Üçünün üçü de ters döndü ve yere çarptı.** En temiz durum bile —
bozucu yok, düz girildi — 179.6° roll'e gidip 11.7 m/s ile çarpıyor. Yani
"motorları kesmekten kesinlikle daha iyi" savı nicel olarak sınırda (11.7 vs
26.2 m/s), nitel olarak yanlış: bu kurtarılmış bir uçuş değil, biraz
yavaşlatılmış bir düşüş.

Mekanizma adım 29/30'un bulduğuyla aynı: **hız sönümlemesi duruş tutmak
değildir.** Artık torklar duruşa sınırsız integre olur; araç yattıkça açık
çevrim Fz yer çekimine karşı koymayı bırakır; hız arttıkça kanat momentleri
devreye girer ve süreç hızlanır.

**Tasarımın bir parçası ÇALIŞTI ve korundu:** dikey politika.
`FS_FZ_OPENLOOP = 0.97`, duruş düz tutulduğunda 49.5 s boyunca ortalama
0.71 m/s alçalma verdi — irtifayı neredeyse tuttu. Başarısız olan `omega_sp = 0`.
Açık çevrim itki "z gitti"nin iyi bir cevabı; hız sönümlemesi "duruş gitti"nin
cevabı değil.

**Uygulanan değişiklik (seçenek 2).** `FsLevel` artık NONE / NO_POS / NO_ALT.
Duruş kestirimi kademelendirilebilir bir girdi değil, **sert ön koşul**:
kaybolursa `Run()` çıkışı keser, tek seferlik bir `attitude LOST` hatası basar
ve `resetState()` çağırır (aksi halde LESO/integral/gölge aktüatör durumu
donar ve duruş geri gelirse artımlı yasa gerçeği tarif etmeyen bir gölgeden
devam ederdi). Uygulama detayları:

- `terminationCommanded()`'ın "iki nedeni de komut edilmiş" yorumu düzeltildi
  — adım 34 çürütmüştü, tek insan kararı `manual_lockdown`.
- `FsLevel` değeri **3 bir daha kullanılmayacak**: adım 35 öncesi loglarda
  "duruş gitti ama hâlâ uçuyor" demek. `.msg` dosyasında da böyle işaretlendi.
- `altitudeLoopVz` (orta irtifa kolu) artık **kanıtlanabilir biçimde
  ulaşılamaz**: tek girişi RATE_ONLY'ydi, `EKF2.cpp:1589-1590` yüzünden
  `alt_ok ≡ vz_ok`. Silinmedi, gerekçesiyle bırakıldı (`decelLoop` /
  `TILT_STICTION_BAND` ile aynı disiplin) — ayrı seviye-2 kararına bağlı.

**Bedeli açıkça yazıyorum:** artık *geçici* bir duruş boşluğu (>50 ms, sonra
düzelecek olan) da çıkışı kesiyor; eskiden hız sönümlemeli bir köprü alırdı.
Bu kabul edildi çünkü (a) commander aynı sinyalle ~50 ms sonra zaten
sonlandırıyor — modül onunla yarışmıyor, aynı fikirde olduğunu söylüyor,
(b) ölçüm o köprünün bir yere çıkmadığını gösteriyor.

**SITL doğrulaması (2026-07-30).** `run_failsafe_test.py --level 3` yeniden
yazıldı: ölçütü tersine çevrildi, artık "bozulup uçtu mu" değil "temiz,
kayıtlı ve zamanında kesti mi". Sonuç **GEÇTİ** — son `vehicle_attitude`
örneği t=48.83 s, modülün kesmesi t=48.87 s (**36 ms gecikme**), commander'ın
`lockdown`'ı t=48.93 s (**kesmeden 64 ms SONRA**, yani kararı modül verdi),
kesmeden sonra %100 NaN, ve arm'dan enjeksiyona kadar 11226 örnekte **%0.000
NaN** (adım 32'nin taşma hatası için regresyon koruması). Zorunlu
`sitl-lockup-check` de geçti (itki sat %0.00, BIG_M 0, itki 10.33-19.43 N,
yaw +4.06°, |vz|max 0.517, irtifa RMS 0.059 m) — adım 31 taban çizgisiyle
denk.

**Seviye 2 (NO_ALT) neden tetiklenemedi — ve muhtemelen ÖLÜ DAL.** İlk deneme
GPS 3B hızını açık bıraktı (dikey hız oradan besleniyordu). İkinci deneme tüm
dikey yardımı kapattı, ama `z_valid` 12 s boyunca hiç düşmedi. Yapısal sebep:
`EKF2.cpp:1589-1590`'da `z_valid` ve `v_z_valid` **aynı OR ifadesi**, yani
modülde `alt_ok ≡ vz_ok`. Bunun iki sonucu var: (a) NO_ALT ancak attitude
sağlamken dikey geçerlilik düşerse oluşur, (b) irtifa dalındaki orta kol
(`altitudeLoopVz`, `FS_DESCENT_VZ` ile kontrollü alçalma) `!alt_ok` iken
**asla** koşamaz — yalnızca RATE_ONLY + geçerli lpos durumunda, o da attitude
kaybının lpos'tan bağımsız olmasını gerektirir. `estimator_status_flags` ≥1 Hz
yayınlandığı için `tilt_aligned`'ın 3 s penceresi bu kapıyı da kapatıyor.

**✅ ADIM 36 (2026-07-30) — SEVİYE 2 / `altitudeLoopVz` KARARI VERİLDİ, ve
yukarıdaki paragrafın İKİ İDDİASI DA ÖLÇÜMLE DÜZELTİLDİ.**

**Düzeltme 1: `altitudeLoopVz` ölü kod DEĞİL.** `altitudeLoop()` onu her
`ALT_TS` çevriminde çağırıyor (`TiltrotorIndiControl.hpp:334`) — yani her
uçuşta, nominal yolda koşuyor. Ölü olan şey fonksiyon değil, onun **ikinci
çağıranıydı**: `else if (vz_ok)` failsafe kolu. Adım 34'ün kaydı bu noktada
yanlıştı.

**Düzeltme 2: NO_ALT ulaşılamaz DEĞİL.** Adım 34 iki denemeden sonra
"tetiklenemedi" demişti; ulog'da `fs=2` **görüldü** (`07_05_51.ulg`,
seviye dizisi `[0, 1, 2]`). Doğru enjeksiyon `EKF2_GPS_CTRL = 0` — yani
**tüm** yardımın kesilmesi. Adım 34'ün iki denemesi de en az bir kaynağı ayakta
bırakıyordu.

**Karar ve gerekçe.** Ölü kol **KALDIRILDI** (ulaşılabilir kılınmadı). Kolun
ihtiyaç duyduğu durum "z geçersiz, vz geçerli"; bu durum **üretilemiyor**.
Kaynak: `EKF2.cpp:1588-1590` ikisini de **tek bir OR**'dan türetiyor, üstelik
"bazı tüketiciler ikisinin farklı olmasını doğru işlemiyor" diyen bir TODO ile.
Kolu ulaşılabilir kılmak, kestirimcinin **açıkça yapmayı reddettiği** bir ayrımı
uydurmak olurdu — yani sınanmamış bir failsafe varsayımı, ki adım 35 onun
bedelini ölçtü. `decelLoop`'tan farkı: `decelLoop` **ölçülmüş olumsuz bir
sonucu** kaydediyor (tekrarlanmasın diye saklanır), bu kol ise yalnızca bir
varsayımdı. `FS_DESCENT_VZ` kaldı — tek kullanıcısı artık **link kaybı** yolu.

**`probe_no_alt.py` — üç konfigürasyon, tahmin yerine ölçüm.** (Adım 34 iki kez
tahmin edip iki kez tutturamamıştı; bu betik `estimator_status_flags`'ı
örnekleyerek hangi kaynağın ayakta kaldığını **görüyor**.)

| aşama | param | sonuç |
|---|---|---|
| A | `BARO_CTRL=0`, `GPS_CTRL=1` | `z_valid` **TRUE kaldı**, `z` −20.04'te **DONDU** |
| C | A + `HGT_REF=2` (var olmayan kaynak) | aynı: `z_valid` TRUE, `z` −20.39'da dondu |
| B | `BARO_CTRL=0`, `GPS_CTRL=0` | `fake_hgt` → `z_valid` **anında false**, `fs=2` |

**Sonuç: "z geçersiz, xy geçerli" durumu PX4 param yüzeyinden üretilemiyor.**
Yükseklik yardımı kesilip yatay yardım devam ederse EKF2 dikey kestirimi
**geçerli ilan etmeye devam ediyor**. Seviye 2'ye ancak tüm yardımı keserek
varılıyor, o da xy'yi götürüyor, o da commander'ı TERMINATION'a sokuyor —
ölçüldü: **fs=2 penceresi 0.02 s**, lockdown 20 ms sonra. **RATE_ONLY'yi
öldüren yapısal tavanın aynısı.** Bu yüzden `--level 2` ölçütleri modülün
kontrol ettiği şeye indirgendi (seviye raporlandı mı, o sırada motorları
kesmedi mi — ikisi de ✅); commander'ın sonlandırması başarısızlık değil,
**kaydedilen bir tavan**.

### 🔴 B1-a — YENİ TEHLİKE: kısmi yükseklik kaybında kestirim SESSİZCE YANLIŞ

Yukarıdaki A ve C aşamalarının asıl bulgusu seviye 2 değil. O konfigürasyonlarda
EKF'in `z`'si **donuyor ve `z_valid` TRUE kalıyor**, oysa araç gerçekten
alçalıyor:

| aşama | EKF `z` | gz yer gerçeği | süre |
|---|---|---|---|
| A | −20.04 (sabit) | 19.95 → **10.15 m** | 22 s |
| C | −20.39 (sabit) | 20.01 → **17.89 m** | 21 s |

Yani A'da **10 m'lik gerçek irtifa kaybı** kestirimde hiç görünmedi ve hiçbir
failsafe tetiklenmedi. **Modülün geçerlilik kapısı bunu yapısal olarak
göremez** — `z_valid`/tazelik testlerinin ikisi de "sinyal var ve taze" diyor;
yanlış olan **değerin kendisi**. Altitude döngüsü bir kurguyu uçuruyor.

Bu, adım 32'nin düzelttiği "durmuş kestirim sağlıklı görünüyor" hatasının bir
üst seviyesi: orada sinyal bayattı, burada **taze ve yanlış**. Donanımda baro
tıkanması / GPS yükseklik kaybı bunun gerçek muadilleri.

- [ ] **Çapraz kontrol gerekli**: `z`'yi bağımsız bir kaynakla (baro ham,
      rangefinder, GPS yükseklik) karşılaştırıp sapma eşiği aşılırsa bozulma
      ilan et. Şu an modülde hiçbir tutarlılık kontrolü yok — yalnızca
      geçerlilik bayrağı ve tazelik.
- [ ] İlk uçuşta bunun gerçekten olup olmadığını görmek için ölçüm: log'a
      `z` ile bağımsız yükseklik kaynağının farkı yazılmalı

**Kalan işler:**
- [x] ~~Açık karar (önce MATLAB'da rate-only ölçümü)~~ — **Adım 35'te kapandı:**
      ölçüldü, RATE_ONLY kaldırıldı, SITL'de doğrulandı
- [x] ~~Seviye 2 / `altitudeLoopVz` ölü dal~~ — **Adım 36'da kapandı:** ölü kol
      kaldırıldı, fonksiyon kaldı (ölü değildi), NO_ALT'ın ulaşılabilir ama
      commander tarafından 0.02 s'de kesildiği ölçüldü
- [ ] **Yeni:** B1-a (sessizce yanlış `z`) — yukarıdaki iki kalem
- [ ] Pilot girişi (Adım 33) **hiç çalıştırılmadı**: SITL'de RC yok, yani
      `manual_control_setpoint` hiç yayınlanmıyor. MAVLink `MANUAL_CONTROL`
      mesajı (pymavlink) bu yolu SITL'de sürebilir — yapılmadı.
- [ ] Bağımsız **kill switch** (tercihen ESC/güç seviyesinde, yazılımdan bağımsız)
- [ ] `publishDisarmed()`'ın gerçek ESC'lerde ne yaptığı doğrulanmalı: NaN
      yazıyor; gerçek ESC/servo bunu nasıl yorumluyor? **Adım 35 bunu daha
      önemli hale getirdi**: duruş kaybı artık bu yolu kullanıyor, yani NaN'ın
      donanımdaki anlamı bir failsafe davranışı oldu, yalnızca kill değil.
- [ ] **Geçici duruş boşluğu**: adım 35'ten sonra >50 ms'lik bir
      `vehicle_attitude` kesintisi çıkışı kesiyor. **SITL tarafı ölçüldü
      (Adım 37, `sitl/check_output_cuts.py`): bugünün 8 uçuşunda boşluk max
      8-16 ms, p99 4 ms → `FS_ATT_TIMEOUT_US`'a 3.1-6.2× pay, ve havada
      0 NaN çıkış.** Ama bu yalnızca bir ALT SINIR: gerçek EKF'te (donanım,
      titreşim, GPS glitch) dağılım farklıdır, **yerde/tetherli yeniden
      ölçülmeli** — çıkarsa `FS_ATT_TIMEOUT_US` yeniden değerlendirilir.
      Aynı tarama adım 31'in loglarında (adım 35 öncesi ikili) **uçuş başına
      3 adet tek-tick havada NaN** buldu; bugünkü kodda yok, ama bu ölçüm
      artık her koşuda otomatik yapılıyor çünkü kimse bakmayınca görünmüyor.
- [ ] Bozulma sırasında **yatay sürüklenme kabul edilmiş bir sonuç**: xy
      geçersizken pozisyon döngüsü kapanmak zorunda ve madde (N) yüzünden araç
      kendini ileri iter (ölçüldü: 14 s'de 0.1 → 2.6 m/s). Kestirim geri
      geldiğinde `pos_hold` **REDDEDİLİYOR** (4.8 m/s > `POS_ENGAGE_V_MAX`
      = 3.0), yani failsafe **kendi kendine toparlanmıyor** — geri geçiş
      (`bt_enable`) toparlanma yoluna bağlanmalı

### 🔴 B2 — Her fiziksel sabit SİMÜLASYONDAN geliyor

`TiltrotorIndiParams.hpp`'deki şu değerlerin tamamı `model.sdf`'ten alınma,
hiçbiri gerçek araçtan ölçülme değil:

| Sabit | Değer | Gerekli iş |
|---|---|---|
| `MASS` | 5.0 kg | Aracı **tart** (bataryalı, uçuşa hazır) |
| `I_XX/I_YY/I_ZZ` | 0.2 / 0.25 / 0.25 | Bifilar sarkaç ölçümü (ya da CAD'den, toleransıyla) |
| `ROTOR_PX/PY/PZ` | ±0.22/0.25/0.06, kuyruk −0.65/0/−0.07 | CG'ye göre **fiziksel ölç** |
| `ROTOR_KF` | 2.0e-5 N/(rad/s)² | Statik itki testi |
| `ROTOR_WMAX` | 1500 rad/s | Gerçek motor/ESC/pervane |
| `ROTOR_TMAX` | ~45 N | Statik itki testi (tek rotor) |
| `ROTOR_KM` | ∓0.06 Nm/N | Tork ölçümü; **işaret** Adım 12'de doğrulandı, **büyüklük** değil |

- [ ] Yukarıdaki tablonun tamamı gerçek ölçümle güncellendi
- [ ] Toplam statik itki / ağırlık oranı ≥ 1.8 doğrulandı (WLS'in manevra payı var mı)

> **Not:** `ROTOR_KM`'nin *işareti* donanıma aktarılabilir (Adım 12, gerçek
> dönüş yönlerinden türüyor) — ama 0.06 değeri SDF `momentConstant`'ından
> geliyor. Yaw'ın tek zayıf ekseni olduğu bu araçta bu büyüklük önemli.

### 🔴 B3 — İtki komut eşlemesi Gazebo'ya özgü

`thrustToNormalized()` (Adım 11'in kök-neden düzeltmesi) tam olarak şunu
tersliyor: `MixingOutput` normalize komutu `SIM_GZ_EC_MIN=10…MAX=1500` rad/s'ye
doğrusal ölçekliyor, sonra gz `T = 2e-5·ω²` uyguluyor. **Gerçek ESC/motor/pervane
zincirinin eğrisi bu değil.**

Bu sadece "kalibrasyon" meselesi değil: WLS'in etkinlik matrisi `dT/du = 1.0`
varsayıyor ve bunu doğru kılan şey tam da bu eşleme. Yanlış eğri = **itkiye
bağlı biçimde yanlış G matrisi** — Adım 11'de bu, düşük itkili rotoru tabana
iten pozitif geri besleme yaratmıştı.

- [ ] Gerçek zincirin itki eğrisi ölçüldü (PWM/DShot komutu → itki, tam aralık)
- [ ] `thrustToNormalized()` bu eğrinin tersiyle değiştirildi
- [ ] Ölçülen `dT/du`'nun çalışma aralığı boyunca ne kadar değiştiği belgelendi

### 🔴 B4 — `ROTOR_PY` işaret bulmacası: **SİMÜLASYON TARAFI ÇÖZÜLDÜ**, fiziksel doğrulama duruyor

**Bulmaca çözüldü (2026-07-30, Adım 34): işaret DOĞRU, çelişki bir çerçeve
dönüşümü hatasıydı — SDF'in kendisinde değil, onu okuyan notta.** SDF `<pose>`
değerleri **model çerçevesinde**, yani gz'nin FLU'sunda (x ileri, y **sol**,
z yukarı); `ROTOR_P*` ise FRD. Dönüşüm `(x, −y, −z)`:

| gz link | SDF pose (FLU) | → FRD | `ROTOR_P*` |
|---|---|---|---|
| `rotor_0` | 0.22, **−0.25**, −0.06 | 0.22, **+0.25**, +0.06 | 0.22, **+0.25**, +0.06 ✅ |
| `rotor_1` | 0.22, **+0.25**, −0.06 | 0.22, **−0.25**, +0.06 | 0.22, **−0.25**, +0.06 ✅ |
| `rotor_2` | −0.65, 0, +0.07 | −0.65, 0, **−0.07** | −0.65, 0, **−0.07** ✅ |

FLU'da y=−0.25 zaten **sağ** demek, yani SDF'in "Right wing rotor" yorumu da
doğru. Üç sütun da birebir uyuyor — ve dikkat, sabitler `motor_N` değil
**`rotor_N`** link pozisyonlarına (itkinin uygulandığı yer) uyuyor, ki doğrusu
o. Adım 4'te işaret çevirme denemesinin MATLAB'da regresyona yol açması bu
sonucu **destekliyor**: orijinal değer doğruydu.

`ROTOR_KM` işaretleri de aynı zincirde tutarlı çıktı. gz sürükleme torkunu
rotorun **dönme eksenine** uyguluyor (`−turningDirection·T·km`) ve o eksen
motorla birlikte eğiliyor. rotor_0 (ccw, dir=+1) için
`τ(FLU) = −km·T·(sin δ, 0, cos δ)` → `τ(FRD) = (−km·T·sin δ, 0, +km·T·cos δ)`.
Kontrolcü ise `m_i = km_i·T_i·dir_i`, `dir_i = (sin δ, 0, −cos δ)` ve
`km_0 = −0.06` ile tam aynısını veriyor (`effectiveness_matrix.m:22-26`) —
**tilt bağımlılığı dahil**: eğim büyüdükçe reaksiyon torkunun roll bileşeni
büyüyor, yaw bileşeni küçülüyor. Bu geri geçiş rejiminde (δ → 90°) önemli ve
doğru modellenmiş.

**Yani "MATLAB kendi içinde tutarlı olduğu için görmüyor" argümanına artık
ihtiyaç yok: SITL'de plant (Gazebo) ile kontrolcü (PX4) bu sabiti
PAYLAŞMIYOR** ve araç kararlı uçuyor, duruşunu 0.06 m'de tutuyor — yani
geometri gerçek plant'a karşı zaten doğrulanmış durumda.

**Ama bu bir TÜRETME, donanım ölçümü değil.** Gerçek araçta hangi motorun nerede
olduğu, hangi yöne döndüğü ve kanal eşlemesi hâlâ elle doğrulanmalı — bunlar
Adım 11/12 ile aynı sınıf riskler ve bu projede iki kez gerçekleşti. Aşağıdaki
kutular bu yüzden açık kalıyor. Kodun içindeki eski not
(`TiltrotorIndiParams.hpp:57-68`, "opposite sign from {0.25,-0.25,0}") artık
yanlış; düzeltilmesi gerekiyor.

- [ ] Hangi motorun fiziksel olarak sağda/solda olduğu **elle doğrulandı**
- [ ] Her rotorun dönüş yönü (CW/CCW) **gözle doğrulandı** ve `ROTOR_KM`
      işaretleriyle karşılaştırıldı
- [ ] Motor çıkış kanal sırası (0/1/2) fiziksel motorlarla eşleşiyor
- [ ] Tilt servo kanalları (5/6/7) fiziksel servolarla eşleşiyor ve **yönleri**
      doğru (komut +1 → gerçekten 90°, komut −1 → gerçekten 0°)

### 🟠 B5 — Geri geçiş var ama yalnızca SITL'de; (R) ve (S) kapandı, (T) açık

*(2026-08-03, Adım 39: 🔴'dan 🟠'a İNDİRİLDİ. Madde (S) kapatıldı — eşik ve
fren marjı artık yasanın kontrol ettiği ekseni (gövde ileri hızı) okuyor — ve
düzeltme, rejimi deterministik kuran yeni bir probe ile sınandı. Geriye 🟠
madde (T) ve **B5'in asıl sebebi: manevra hiç gerçek donanımda uçmadı** kalıyor.
`fx_trim` bağımlılığı da (aşağıda) sürüyor.)*

*(2026-07-31, Adım 38: 🟠'dan 🔴'a ÇIKARILMIŞTI. Madde (R) kapandı, ama aynı
doğrulama madde (S)'yi ortaya çıkardı — fren yasası aracı geri yönde
12.8 m/s'ye kaçırabiliyor. Bir engelleyicinin durumu, en ağır açık maddesine
göre belirlenir.)*

*(Adım 31, 2026-07-29 ile daraltıldı; Adım 30'daki hâli 🔴 "seyirden
hover'a dönüş yolu YOK" idi.)*

Adım 30'da araç **tek yönlüydü**: seyre çıkabiliyor, dönemiyordu. Adım 31
bunu çözdü ve engelleyici 🔴'dan 🟠'a indi — **kapanmadı**, çünkü gerçek
donanımda hiç uçmadı.

> **⚠️ GÜNCELLEME 2026-07-30 (Adım 37): Adım 31'in "doğrulandı" sonucu
> MARJİNALMİŞ ve bugün iki kez BAŞARISIZ oldu.** GUI'li yeniden koşumda manevra
> iki bağımsız uçuşta **devir hızının üstünde takıldı** (v_h 3.2-3.5 m/s'de
> 90+ s kararlı denge; `BT_HANDOFF_V = 3.0`'a hiç inemedi, yani `pos_hold` hiç
> istenmedi). Sebep ölçüldü: fren yasası pitch'i hızla söndürürken yenmesi
> gereken ileri kuvvet **sabit** (δ1/δ2 tabanda çakılı → yaw trimi δ0'ı 10-15°'de
> tutuyor → sürekli 3.1-4.1 N). Yalnızca *durmak* için gereken açı
> `asin(fx_trim/(m·g)) = 3.39°`, `BT_PITCH_MAX`'in (4°) hemen altında.
> Adım 31'in iki uçuşu eşiği ancak sürüklenme sayesinde geçmiş — birinde son
> 0.5 m/s **12.1 s** sürmüş.
>
> **Düzeltildi ve doğrulandı:** fren yasası ayrıştırıldı
> (`pitch = BT_TRIM_PITCH + BT_PITCH_MAX·fade`, ilk terim sönmez ve `FX_TRIM`'e
> bağlı), `BT_BRAKE_V_FULL` `BT_HANDOFF_V`'ye bağlandı. İki bağımsız uçuş,
> ikisi de tam dizi: 15.38/14.66 m/s → 0.13/0.07 m/s, BRAKE evresi 92-99 s'lik
> takılmadan **5.7-6.1 s**'ye indi, yaw −3.4/+1.1°, irtifa bandı 1.11-1.14 m,
> itki doyumu %0.00, 0 BIG_M; zorunlu `sitl-lockup-check` geçti. Ayrıntı:
> rapor Adım 37.
>
> **🔶 AYNI OTURUMDA İKİNCİ BİR KUSUR BULUNDU — madde (R).**
> Fren düzeltmesi doğrulandıktan sonraki iki uçuşta manevra bu kez **RETRACT**
> evresinde takıldı: tavan 9°'ye indikten sonra araç oraya asimptotik yaklaşıyor
> ve **terminal hız 8.0-9.3 m/s**, yani `BT_RELEASE_V = 8.0`'ın üstünde —
> dolayısıyla çıkış koşulu hiç sağlanmayabiliyor (bir uçuşta 200 s boyunca
> sağlanmadı). Tamamlanan uçuşlar eşiği ilk yavaşlama geçicisinde geçmiş.
> **Tehlikeli kısmı süre değil, o sırada bulunulan konfigürasyon:** tavan tam
> trim değerinde otururken δ0 çakılı kalıyor ve yaw'ın modülasyon otoritesi
> sıfırlanıyor (adım 31/Faz 2'nin ölçtüğü mekanizma) — 200 s'lik uçuşta yaw
> **+117.7°** sürüklendi. Yani geri geçiş **SITL'de bile garanti tamamlanan bir
> manevra değil: 8 uçuşun 5'i tamamladı.**
>
> **✅ MADDE (R) KAPATILDI — ADIM 38 (2026-07-31).** Adım 37'nin iki seçeneği
> arasında seçim yapılmadı, **ikisi birden** uygulandı, çünkü farklı şeyleri
> garanti ediyorlar: (1) `BT_RELEASE_V` 8.0 → **10.0** — eşik ölçülen terminal
> aralığın dışına taşındı; (2) **`BT_FLOOR_DWELL = 20 s` (yeni)** — tavan tabana
> vardıktan sonra bu süre geçerse hıza **hiç bakmadan** BRAKE'e geçilir. İkincisi
> aero-bağımsızdır ve asıl donanım gerekçesidir: 10.0 sayısı Gazebo aerodinamiğinden
> geldi, gerçek kanat farklı sürüklerse eşik yine dengenin içine düşer — ama süre
> terimi terminal hız ne olursa olsun geçerlidir, yani **sınırsız bir arızayı
> sınırlı bir gecikmeye çevirir**. İptal değil BRAKE seçildi: bekleme,
> RETRACT'ın verebileceği en düşük hızda dolar ve BRAKE tavanı yükselterek
> yaw otoritesini zaten geri verir.
> **Doğrulama:** üç bağımsız normal uçuş, üçünde de tam dizi (RETRACT 16.5-20.9 s
> — eskiden 21.9-25.1 s ve takılan uçuşlarda 111/200 s; son v_h 0.09-0.24 m/s,
> yaw −2.4…−6.0°, irtifa bandı 1.38-1.56 m); artı **kancalı bir build ile
> (`BT_RELEASE_V = 5.0f`) emniyet yolu bilerek tetiklendi** ve 6.6 m/s'de
> `[via FLOOR_DWELL backstop]` olarak çalıştığı ölçüldü. MATLAB tarafında
> plantsız bir durum makinesi testi eklendi (`run_backtrans_sm_test.m`, 6/6),
> regresyon birebir nötr. Ayrıntı: rapor Adım 38.
>
> **⚠️ AMA B5 YİNE KAPANMADI — çünkü doğrulama YENİ BİR KUSUR ORTAYA ÇIKARDI:
> madde (S), aşağıda.**
>
> ### ✅ madde (S) KAPATILDI (Adım 39, 2026-08-03) — eşik ve fren marjı artık gövde ileri hızını okuyor
>
> **Düzeltme iki yerde, tek ilkeden: bir eşik, yasasının KONTROL ETTİĞİ ekseni
> okumalıdır.** (1) `BRAKE → HANDOFF` koşulu **işaretli** gövde ileri hızını
> okur (`v_fwd < BT_HANDOFF_V`); `v_fwd < 0` de geçerli bir çıkıştır, çünkü
> BRAKE'in işi ileri hızı bitirmekti ve bitmiştir — mutlak değer almak aynı
> hatayı tekrarlardı. (2) Frenleme **marjı** da `max(0, v_fwd)` ile söner, yani
> araç geri gitmeye başlarsa marj SIFIRLANIR ve geriye yalnızca duruş trimi
> kalır; **kaçışı fiilen durduran terim budur.** RETRACT bilerek `v_h`
> (büyüklük) okumaya devam ediyor: oradaki soru aerodinamiktir ("kanat hâlâ
> taşıyor mu"), cevabı hava hızının büyüklüğüdür.
>
> **Doğrulama:** iki normal uçuş (15.21/15.76 → 0.21/0.12 m/s, BRAKE 8.5/9.1 s,
> yaw −2.2/−2.6°, irtifa bandı 1.53/1.54 m, %0.00 doyum, 0 BIG_M) + kancalı
> uçuş (`BT_RELEASE_V = 5.0f`, emniyet yolu yine çalıştı: 6.64 m/s'de
> `[via FLOOR_DWELL backstop]`); plantsız durum makinesi testi 9 gruba çıktı
> (13/13, ve test 8 eski büyüklük mantığının aynı izde 300 s takıldığını
> gösteriyor); MATLAB regresyonu birebir nötr; zorunlu `sitl-lockup-check`
> GEÇTİ (yaw −1.37°, irtifa RMS 0.275 m).
>
> **Asıl kanıt kancalı uçuştan gelmedi** — o uçuşta yanal sürüklenme yalnızca
> 1.28 m/s'ye çıktı, yani rejim HİÇ KURULMADI. Rejimi deterministik kuran yeni
> bir probe yazıldı (`sitl/probe_lateral_handoff.py`: frenlerken heading +90°
> çevrilir, ölçülen arızanın geometrisi budur): yanal **4.76 m/s**, HANDOFF
> `|v_h| = 5.04` m/s'de gerçekleşti (`v_fwd = +2.87`) — **eski büyüklük koşulu
> o anda sağlanmıyordu**, manevra 0.17 m/s'de tamamlandı.
>
> **⚠️ VE MADDE (S) SANILDIĞI KADAR EGZOTİK DEĞİLMİŞ (Adım 39b, GUI'li yeniden
> koşum).** `side` kameralı **normal** bir uçuşta yanal sürüklenme hiçbir kanca
> olmadan **3.60 m/s**'ye çıktı — arızayı üreten 3.04'ün üstünde — ve HANDOFF
> `v_h = 3.58`, `v_fwd = 2.99`'da gerçekleşti, yani **eski büyüklük koşulu o
> anda da sağlanmıyordu: düzeltme olmasaydı bu sıradan uçuş da takılırdı.**
> Dört normal uçuşta ölçülen yanal 1.04 / 1.28 / 1.49 / 1.90 / **3.60** m/s,
> yani dağılımın kuyruğu eşiği rahatça aşıyor. Adım 38'de maddenin yalnızca
> kancalı uçuşta görünmesi, arızanın nadir olmasından değil, o uçuşun UZUN
> olmasındandı. Sonuç yine temiz: yeniden-hızlanma 0.00, yaw +0.8°, irtifa
> bandı 1.23 m, %0.00 doyum.
>
> **Kalıntı (kapatılmadı, ÖLÇÜLDÜ):** `POS_ENGAGE_V_MAX` hâlâ bir büyüklük
> kapısı, yani handoff ileri eksende istenip hold tarafından reddedilebiliyor
> ve her tick yeniden deneniyor. Ölçüldü: normal uçuşlarda **0.22 / 0.56 s**,
> ağır yanal sürüklenmeli probe'da **3.23 s** — ve o süre boyunca `v_h` 5.04 →
> 3.00 ile azalmaya devam etti, pitch trimde kaldı, kaçış olmadı. Kapıyı yön
> duyarlı yapmak Adım 29'un güvenlik gerekçesine dokunur ve kendi ölçümünü
> hak eder. Modül >0.5 s'lik her beklemeyi WARN olarak yazıyor.
>
> **Test altyapısı da düzeltildi ve bu ayrı bir bulgu:** madde (S)'yi yakalasın
> diye eklenen 6. ölçüt önce "işaretli ileri hız ≥ −2.0 m/s" idi ve probe'da
> KALDI (−3.95) — oysa araç kaçmamıştı, `v_h` monoton 9.74 → 3.00 iniyordu;
> sebep heading'in aynı pencerede **+186.7°** dönmesi, yani ölçüt DÖNEN bir
> çerçeveye izdüşüme bakıyordu. **Ölçüt, kontrol yasasının yaptığı hatanın
> aynısını yapmıştı.** Şimdi çerçeveden bağımsız: fren penceresinde `v_h`'nin
> koşan minimumundan **yeniden-hızlanması ≤ 1.0 m/s**, ve **gerçek arıza
> log'una karşı doğrulandı** (14_13_11: 10.31 m/s → KALDI; dört yeni uçuş:
> 0.00 → GEÇTİ). Ölçüt penceresi de daraltıldı ("fren yasasının pitch'e sahip
> olduğu" aralık), bunun için `TiltrotorIndiStatus.msg`'e `pos_hold_active`
> eklendi.
>
> **Aşağıdaki bölüm arızanın ÖLÇÜLDÜĞÜ hâli — kayıt olarak duruyor.**
>
> ### ~~🔴 madde (S)~~ — HANDOFF eşiği YANLIŞ SİNYALE bakıyor, fren yasası aracı GERİ kaçırıyor
>
> *(Adım 38, 2026-07-31 — madde (R)'nin SEBEBİ DEĞİL, ondan bağımsız ve önceden
> var olan bir kusur; emniyet yolunu doğrulayan kancalı uçuşta görünür oldu.
> **Adım 39'da kapatıldı, yukarı bakın.**)*
>
> `BRAKE → HANDOFF` koşulu `v_h < BT_HANDOFF_V = 3.0` ve `v_h` bir
> **BÜYÜKLÜK** (`hypot(vx,vy)`). Fren yasası ise yalnızca **ileri** ekseni
> kontrol ediyor. Ölçüm (`sitl/diag_brake_reversal.py`, log 14_13_11):
> `min|v_h| = 3.08 m/s` iken **gövde ileri hızı u = −0.51 m/s, yanal hız
> v = +3.04 m/s** — yani araç ileri yönde çoktan durmuştu ama eşiğin üstünde
> tutan şey **yanal sürüklenmeydi**. Handoff hiç istenmedi, sönmeyen fren
> pitch'i (3.39° trim + 4.0° marj) itmeye devam etti ve araç **geri yönde
> 12.8 m/s'ye kaçtı**. Aynı uçuşta beş kez tekrarlandı (13.4 / 7.9 m/s …).
> Yanal sürüklenmenin kaynağı yapısal: **RETRACT/BRAKE boyunca yanal eksende
> hiçbir kontrol yok**, pozisyon döngüsü ancak HANDOFF'ta devreye giriyor.
>
> **Bu, aynı hastalığın ÜÇÜNCÜ tekrarı** (Adım 37 = otorite sönüyordu,
> madde (R) = eşik dengede oturuyordu, madde (S) = eşik yanlış eksene bakıyor).
> Üç normal uçuşta görülmedi çünkü BRAKE yalnızca 8.9-9.8 s sürdü ve yanal
> sürüklenme birikemedi — **ama emniyet devreye girdiğinde manevra uzuyor, yani
> (R)'nin çözümü (S)'yi daha ERİŞİLEBİLİR kılıyor.** Aday çözüm (ölçülmedi,
> uygulanmadı): eşiği gövde ileri hızına bağlamak ve/veya işaret değişiminde
> pitch'i kesmek. **Donanımda geri geçiş bu madde kapanmadan denenmemelidir.**
>
> ### 🟠 madde (T) — `attitude LOST (tilt=0)` uçuş ortasında tetikleniyor
>
> İki kancalı uçuşta üç kez görüldü (normal uçuşların hiçbirinde yok): Adım 35'in
> sert ön koşulu tetiklenip çıkışı kesti ve geri geçiş durum makinesini
> **sıfırladı** (manevra tavan bırakılmış hâlde baştan başladı). `tilt_aligned`
> hem `estimator_status_flags`'in 3 s'den taze olmasına hem `cs_tilt_align`'a
> bağlı, ve EKF2 bu topic'i **~1 Hz** yayınlıyor. İki mekanizma da mümkün:
> topic bayatladı (sağlıklı EKF'de çıkış kesilir) ya da EKF şiddetli uçuş
> durumunda hizalamayı gerçekten düşürdü.
>
> **ADIM 39 GÜNCELLEMESİ (2026-08-03) — ENSTRÜMAN KURULDU, ama madde
> TEKRARLANMADI, ve tekrarlanmamasının kendisi bir bulgu.** Topic log profiline
> eklendi (`sitl/logger_topics_shadow.txt`). Dört uçuşun hiçbirinde
> `attitude LOST` görülmedi; ölçülen yayın aralığı ortalama **0.93-0.96 s, max
> 1.00 s** (3 s'lik tazelik penceresinin çok altında, >3 s olan hiç yok) ve
> `cs_tilt_align` her örnekte 1. Yani **bu koşullarda "topic bayatladı"
> mekanizması için kanıt yok.** Ama (T)'nin görüldüğü uçuşlar madde (S)'nin
> **geri kaçış** uçuşlarıydı (12.8 m/s), ve o rejim artık oluşmuyor — yani
> tetikleyici koşulun kendisi ortadan kalkmış olabilir. **Madde açık kalıyor**
> (🟠): bir daha görülürse hangi mekanizma olduğu artık tahmin edilmeyecek,
> log'dan okunacak. Tekrarlanmasının en olası yolu şiddetli manevra; kasıtlı
> bir tekrar denemesi yapılmadı.
>
> **Donanım açısından bunun anlamı, B5'i kapatmaya YAKLAŞTIRMAK DEĞİL, tam
> tersi.** `BT_TRIM_PITCH` doğrudan `FX_TRIM = 2.9 N`'den türüyor ve o değer
> *simüle edilmiş* trimin ölçümü (aşağıdaki §4 maddesi zaten bunu açık
> bırakıyor). Gerçek araçta yaw triminin doğurduğu ileri kuvvet farklıysa fren
> yasasının ilk terimi de yanlış olur — üstelik artık manevranın tamamlanıp
> tamamlanmaması buna DOĞRUDAN bağlı. **`fx_trim` ölçümü B5 için de bir
> ön koşul hâline geldi.**

**Ne yapıldı.** Dört durumlu bir geri geçiş modu (`backtrans_loop.m` /
`backTransition()`, `bt_enable` setpoint bayrağı):
RETRACT (kanat tilt tavanı 2 °/s ile 9°'ye iner) → BRAKE (tavan 20°'ye
**yükseltilir**, ≤4° burun yukarı frenleme) → HANDOFF (`pos_hold`
devralır). İki otomatik uçuş, `bt_enable` dışında hiçbir komut yok:
13.5/14.5 m/s → 0.12/0.09 m/s, yaw toplam dönüş −10.1°/−8.1°, irtifa
bandı 0.95 m, itki doyumu %0.00, sıfır BIG_M. `sitl-lockup-check` geçti.

**Adım 30'un teşhisi eksikti, düzeltildi.** "Frenleme otoritesi tilt'tir"
doğru, ama tilt'i ileri süren şey Fx'in zayıflığı değil **irtifa (Fz)
kanalı**: tahsisat her örnek için çevrimdışı yeniden çözülüp atıf
yapıldı — Fz talebini sıfırlamak sürüklenmeyi tersine çeviriyor
(+0.64 → −0.45 °/s), Fx talebini sıfırlamak hiçbir şey değiştirmiyor.
Bu yüzden tilt bir **kutu kısıtıyla** sürülür, ağırlıkla değil
(`Ws_Fz/Ws_Fx = 400`, ve Ws_Fx'i o mertebeye çıkarmak Adım 7'de yaw'ı
bozmuştu).

**Donanım açısından ne değişti, ne değişmedi.** Araç artık tek yönlü
değil — ama bu **yalnızca Gazebo'da** gösterildi. Donanımda seyir hâlâ
**denenmemeli**, üç somut nedenle:
1. Manevranın her eşiği (`BT_RETRACT_RATE`, `BT_CEIL_FLOOR = 9°`,
   `BT_RELEASE_V = 8 m/s`, `BT_BRAKE_CEIL = 20°`) **SITL'de ölçüldü** ve
   hepsi aerodinamiğe bağlı. Gazebo modelinde beş lift-drag yüzeyi var;
   gerçek kanat farklı taşırsa bu eşiklerin hepsi kayar. MATLAB bu
   manevrayı yapısal olarak üretemiyor (tek boylamsal yüzey, 12 m/s'de
   ~25 N), yani **ikinci bir bağımsız doğrulama ortamı yok** — B2/B3 ile
   aynı sınıf risk.
2. `BT_CEIL_FLOOR`'un altına inmek **yaw'ı aç bırakıyor**: taban 9/7/5°
   süpürmesinde yaw sapması +0.0205/+0.0308/+0.0384 rad/s (süpürme sırası
   ters çevrilerek doğrulandı) ve 5°'de araç kendiliğinden kaçtı. Sebep
   yapısal: δ1 `TILT_MIN`'de çakılı olduğu için diferansiyel tam olarak
   tavana eşit, ve δ1 = 0 iken `τ_z = −0.25·Fx` — yaw trim torku ile kalan
   ileri kuvvet **aynı büyüklük**. Gerçek araçta trim farklı çıkarsa
   (bkz. `fx_trim` maddesi) bu sınır da kayar.
3. `bt_enable`'ın tek kaynağı hâlâ `test_sp` konsol komutu — **pilot
   tetikleyemez, iptal edemez** (B1). Geri geçiş 30-40 s sürüyor ve bu
   süre boyunca müdahale yolu yok.

**Kapanma koşulu:** B2+B3 ölçüldükten sonra eşiklerin gerçek aero ile
yeniden türetilmesi, B1'in çözülmesi (pilotun başlatıp iptal edebilmesi),
ve manevranın önce yüksek irtifada, bol paylı bir uçuşta denenmesi.
Şu anki `BT_MIN_ALT = 15 m` SITL'de ölçülen ≤1 m'lik irtifa bandına göre
seçildi; donanımda bu pay çok daha geniş tutulmalı.

---

## 1. Tezgâh testleri (pervanesiz, sonra pervaneli-bağlı)

### Sensör / kestirim
- [ ] 🔴 Magnetometre kalibrasyonu + **yaw kestirim hatası** kontrolü.
      SITL'de EKF yaw'ı gerçek yönelimden **5-10° sapıyordu** (Adım 27); orada
      ground truth vardı, donanımda **yok**. Kontrolcü *kestirilen* yaw'ı
      tuttuğu için bu hata doğrudan fiziksel yönelim hatasına dönüşür.
- [ ] 🔴 IMU/gyro kalibrasyonu; `vehicle_angular_velocity.xyz_derivative`
      gürültüsü ölçüldü — **INDI'nin tüm sönümlemesi bu sinyalden geliyor**
      (SITL'de gecikme 4-8 ms, HF gürültü sinyalin %4'üydü; Adım 20)
- [ ] 🟡 Titreşim (vibe) seviyeleri kabul aralığında — pervane dengesizliği
      `omega_dot` üzerinden doğrudan INDI'yi bozar

### Aktüatör
- [ ] 🔴 **Tilt servolarının gerçek dinamiği ölçüldü**: `TILT_TAU = 0.15 s`
      birinci derece yaklaşım, ve PX4'te **servo pozisyon geri beslemesi YOK** —
      kontrolcü bir *gölge model* kullanıyor. Gerçek servo bu modelden saparsa
      INDI'nin lineerleştirme noktası ve WLS'in G matrisi birlikte kayar.
      SITL'de sapma p99 ≤ 0.55° idi (Adım 18); gerçek servoda ölçülmeli.
- [ ] 🔴 Servo **stiction/ölü bant** ölçüldü. Adım 24'ün uyarısı kritik:
      ölü bandı gölge modele eklemek **kapalı çevrimi kilitledi** (komut
      artışı ölü banttan küçük → gölge donuyor). Yani gerçek servonun ölü
      bandı `TILT_SLEW_BOX_RATE·TS_BOX = 0.012 rad = 0.69°`'den **büyükse**
      benzer bir kilitlenme riski var.
- [ ] 🔴 Tilt mekanik aralığı gerçekten [0°, 90°] mi — ve **0° gerçekten dikey mi**
      (tüm yaw trim mantığı buna dayanıyor)
- [ ] 🟡 Servo besleme akımı/ısınması sürekli tilt düzeltmesi altında kabul edilebilir

### Tahsisat / emniyet
- [ ] 🔴 `leso_enable_yaw = FALSE` doğrulandı. **Yaw ekseninde LESO açmak
      SITL'de aracı 5 saniyede ters çevirdi** (rapor §4 (H)) — bu ayar
      donanımda asla açılmamalı.
- [ ] 🔴 `RATE_SP_LIMIT = [3.0, 3.0, 0.5]` — yaw'daki **0.5** Adım 13'ün
      düzeltmesi ve yaw'ı çözen şeydi; tek skalere geri dönmek savrulmayı
      geri getirir.
- [ ] 🟡 Arm anında `hoverTrim()` tohumlaması gerçek geometriye göre yeniden
      hesaplandı (B2/B4'ten sonra)

---

## 2. Bağlı (tethered) / kısıtlı ilk çalıştırma

- [ ] 🔴 Araç **fiziksel olarak kısıtlı** (test standı / bağ) hâlde ilk arm
- [ ] 🔴 Motor dönüş yönleri ve kanal eşlemesi düşük gazda gözle doğrulandı
- [ ] 🔴 Tilt servolarının arm anında **doğru yöne** gittiği doğrulandı
      (SITL'de disarm hâlinde NaN yazılıyor, servolar 0°'da duruyor; arm anında
      gölge δ0 ≈ 9.4°'ye tohumlanıyor ve gerçek servo 72 ms'de yetişiyordu)
- [ ] 🔴 Açık çevrim yaw reaksiyon torku işareti ölçüldü ve modelin tahminiyle
      karşılaştırıldı — **Adım 12'de kök nedeni bulan ölçüm tam olarak buydu**
      (tahmin +6.2 rad/s², ölçüm +6.45/+6.56)
- [ ] 🟡 Kısa süreli, düşük irtifada (ip boyu ~30 cm) tutma denemesi

---

## 3. İlk serbest uçuş (kademeli)

Her adımda ≥25 s gözlem (kısa testler bu projede defalarca yanılttı) ve
**yaw'ı açıdan değil hızdan** oku (`vehicle_angular_velocity.xyz[2]`).

- [ ] 1 m irtifada 30 s duruş — `pos_hold` **açık**
- [ ] Sürüklenme, yaw hızı RMS, aktüatör doyumu kaydedildi
- [ ] 3 m'de 60 s duruş
- [ ] ±30° yaw adımı, **her iki yön** (madde (P) asimetrisi)
- [ ] Kademeli iniş, **1.0 m'lik kademelerle** (1.5 m SITL'de 13 aktüatör
      yapışması üretti — Adım 27)

Her uçuşta kaydedilecek bağlam: yatay hız platosu, batarya gerilimi, rüzgâr.

---

## 4. SITL senaryo kapsamı

- [x] 🟢 **Rüzgâr/bozucu reddi — KAPATILDI (2026-07-29).** İlk kez *gerçek
      hover'da* (`pos_hold` açık) koşuldu. 0.4 + 0.15·sin(2π·0.3t) N·m sürekli
      roll bozucusu altında araç duruşunu korudu: sürüklenme ≤0.36 m, v_h
      0.01-0.42 m/s, rate RMS p/q ≈ 0.06-0.09 rad/s, **0 BIG_M**, aktüatör
      yapışması yok, EKF %100 sağlıklı.
- [x] 🟢 **Geçiş senaryosu — KAPATILDI (2026-07-29).** Duruş → `pos_hold`
      bırakma → Fx rampası 0→10 N. **Devir temiz:** bırakma anında hız
      aktivitesi artmıyor, azalıyor (p RMS 0.2123 → 0.1503, max|ω| 0.3642 →
      0.2538) — roll/pitch sahipliğinin ve `fx_trim`'in el değiştirmesi basamak
      üretmiyor. Rampada 0→10.86 m/s, itki `sat_flag` %0.0, irtifa 0.4 m
      içinde, **0 BIG_M**.
- [ ] 🟡 **Rüzgârda duruş, tilt büyürken** — hâlâ test edilmedi. `fx_trim`'in
      `gain_schedule_smooth` ile sönümlenme yolu normal geçişte hiç
      tetiklenmiyor (11 m/s'de bile `smooth` yalnızca 0.090'a çıkıyor, ve
      geçişte `pos_hold` zaten kapalı). Bu fade bir güvenlik payı; aktif
      mekanizma değil. Şiddetli rüzgârda pozisyon tutarken tilt büyürse
      devreye girer — o senaryo koşulmadı.
- [ ] 🔴 **Pozisyon döngüsü YALNIZCA HOVER İÇİNDİR — bu bir varsayım değil,
      ölçülmüş bir sınır (Adım 29).** 14.5 m/s'de devreye alındığında pitch
      `POS_TILT_MAX`'te doydu, hız 9.6 m/s'de kilitlendi ve araç 35 s boyunca
      sürekli tırmandı; sonraki frenleme denemesinde SITL'de **düştü**. Sebep:
      `theta_sp = -atan2(ax_b, g)` düz multikopter bağıntısı, oysa bu aracın
      kanadı var — ~5-6 m/s üstünde burun yukarı bir frenleme değil **tırmanış**
      komutudur ve irtifa döngüsü kanat taşımasını yenemez.
      Yazılımda `POS_ENGAGE_V_MAX = 3.0 m/s` kapısıyla engellendi (SITL'de
      doğrulandı: hover'da kabul, 9.4 m/s'de red, irtifa kaçışı yok).
      **Donanımda:** bu kapıya güvenmeden önce gerçek araçta doğrulanmalı ve
      pilot bu sınırı bilmeli.
- [x] 🟠 **Geri geçiş (B5)** — artık bir engelleyici olarak §0'da izleniyor.
      SITL'de otomatik ve doğrulandı (Adım 31); **Adım 37'de (2026-07-30) bu
      doğrulamanın marjinal olduğu bulundu, manevra iki uçuşta tamamlanmadı,
      fren yasası ayrıştırılarak düzeltildi ve iki uçuşla yeniden
      doğrulandı**; donanımda denenmedi.
- [x] 🟢 **Ölçütler artık makineyle kontrol ediliyor (Adım 37).**
      `sitl/analyze_backtrans.py` beş geri-geçiş ölçütünü ulog'dan hesaplıyor ve
      pencereyi bağımsız bir sinyalden (`bt_state`, yeni telemetri) kuruyor;
      `sitl/check_output_cuts.py` her uçuşta havada NaN çıkış + `vehicle_attitude`
      boşluğu tarıyor. İkisi de `run_backtrans_test.py` sonunda otomatik koşuyor.
      Doğrulaması: adım 31'in loglarında kayıtlı sayıları yeniden üretti ve
      bilinen başarısız uçuşu doğru şekilde eledi.
- [ ] 🔴 **Hızlıyken alçalmayın** (Adım 29): 13-21 m/s'de inişe geçen bir uçuşta
      98+51 BIG_M aktüatör yapışması sayıldı (kanat taşıması alçalmaya direndiği
      için irtifa döngüsü itkiyi sert kısıyor). Doğrulanmış iniş **hover'dan,
      1.0 m kademelerle** → 0 BIG_M.
- [ ] 🟡 Pozisyon döngüsü kazançlarının (`POS_KP_P/KP_V/KI_V`) gerçek kütle ve
      atalet altında yeniden değerlendirilmesi — **yalnızca MATLAB/SITL'de
      ayarlandı**, gerçek donanımda hiç uçmadı
- [ ] 🔴 `fx_trim = 2.9 N` gerçek araçta yeniden ölçülmeli: bu değer
      *simüle edilmiş* trim'in ulaşılabilir denge noktası. Gerçek araçta yaw
      trim'inin doğurduğu ileri kuvvet farklı olacak.
      **🟡 → 🔴 yükseltildi (Adım 37, 2026-07-30):** artık yalnızca duruş
      kalitesini değil, **geri geçişin tamamlanıp tamamlanmadığını** belirliyor.
      Fren yasasının sönmeyen terimi `BT_TRIM_PITCH = asin(FX_TRIM/(m·g))`
      buradan türüyor; SITL'de bu kuvvetin 3.1-4.1 N olduğu ve otoritenin
      (4°=3.42 N) tam bu aralığın içinde kaldığı ölçüldü — yani hata payı dar.
- [ ] 🟡 LESO açık/kapalı farkı SITL rüzgâr testinde **belirsiz** çıktı
      (p'de biraz kötü, q'da biraz iyi), oysa MATLAB'da 3× kazandırıyor.
      Engelleyici değil ama açıklanmamış bir fark.

---

## 5. Hazır olanlar 🟢

Bunlar çözülmüş ve iki bağımsız ortamda doğrulanmış durumda:

- 🟢 Aktüatör kilitlenmesi (Adım 11-12) — sıfır BIG_M, çok sayıda uçuşta
- 🟢 Yaw savrulması (Adım 13) — eksen bazlı `RATE_SP_LIMIT`
- 🟢 Düşük hızda yaw salınımı, madde (Q) (Adım 23, 27) — `TILT_SLEW_BOX_RATE = 3.00`
- 🟢 Yatay sürüklenme, madde (N) (Adım 28) — pozisyon döngüsü, 235 m → 0.06 m
- 🟢 Yaw yön asimetrisi, madde (P) (Adım 28) — `fx_trim`, 7.4× → 1.02×
- 🟢 MATLAB ↔ Simulink ↔ PX4 sabit senkronu (Adım 27-28)
- 🟢 İrtifa kontrolü — tutuş RMS 0.05-0.09 m

---

## Özet

**Kontrol yasası tarafı olgun.** Bu oturumların çözdüğü şeyler gerçek ve iki
ortamda doğrulandı. **Eksik olan kontrol yasası değil, donanım entegrasyonu:**
pilot girişi/failsafe yazıldı ama yarısı ölçülmemiş ya da çalışmıyor (B1 —
kademeli failsafe'in 1. seviyesi doğrulandı, 3. seviyesi commander'ın otomatik
sonlandırmasıyla eziliyor ve araç düşüyor, pilot yolu hiç çalıştırılmadı),
fiziksel parametrelerin hiçbiri ölçülmedi (B2),
itki eşlemesi simülatöre özgü (B3) ve bilinen bir işaret belirsizliği donanımda
tehlikeli hâle geliyor (B4). Beşinci engelleyici B5 (seyirden hover'a dönüş)
Adım 31'de **çözüldü ama yalnızca SITL'de** — eşiklerinin hepsi aerodinamiğe
bağlı ve ikinci bir doğrulama ortamı yok (MATLAB bu manevrayı yapısal olarak
üretemiyor), üstelik pilot onu başlatamıyor da iptal edemiyor da (B1).
**Adım 38'de B5 🟠'dan 🔴'a çıkmıştı:** madde (R) (RETRACT'ın çıkışı dengenin
sınırındaydı) iki terimli bir çıkışla kapatıldı ve üç uçuşla doğrulandı, ama
aynı doğrulama **madde (S)**'yi ortaya çıkardı — `BRAKE → HANDOFF` eşiği hız
BÜYÜKLÜĞÜNE bakıyordu, oysa fren yasası yalnızca ileri ekseni kontrol ediyor;
giderilemeyen bir yanal bileşen eşiği bloke edince sönmeyen fren pitch'i aracı
**geri yönde 12.8 m/s'ye kaçırdı**.
**Adım 39'da (2026-08-03) madde (S) KAPATILDI ve B5 🔴 → 🟠 indi:** hem eşik hem
frenleme marjı artık işaretli **gövde ileri hızını** okuyor (RETRACT bilerek
büyüklükte kaldı — orası aerodinamik bir soru), üç uçuş + rejimi deterministik
kuran yeni bir probe (`probe_lateral_handoff.py`) ile doğrulandı, ve yeni 6.
ölçüt **gerçek arıza log'una karşı** sınandı. Geriye 🟠 **madde (T)**
(`attitude LOST` uçuş ortasında tetiklenip durum makinesini sıfırlıyor; artık
topic loglanıyor ama madde tekrarlanmadı, mekanizma hâlâ ayırt edilmedi) ve
B5'in asıl sebebi kalıyor: **manevra gerçek donanımda hiç uçmadı** ve
tamamlanması `fx_trim`'e (🔴, ölçülmemiş) doğrudan bağlı.

**En kısa güvenli yol:** B2 + B4 (ölçüm ve doğrulama, uçuş yok) → B3 (statik
itki testi) → B1 (RC + kill switch entegrasyonu) → tezgâh → bağlı → kademeli
uçuş. B1 olmadan hiçbir serbest uçuş denenmemeli. **Seyir ve geri geçiş,
B2+B3 ölçülüp eşikler gerçek aero ile yeniden türetilene kadar donanımda
denenmemeli** (B5).

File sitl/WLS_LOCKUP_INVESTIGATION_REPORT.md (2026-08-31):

# WLS Aktüatör Kilitlenmesi / Yaw Savrulması — Araştırma Raporu

> Bu, `RUNBOOK.md` §4'teki canlı araştırma logunun (ham veri, komut
> dizileri, tick-bazlı teşhis) özet/rapor biçimidir. Tam ayrıntı ve
> yeniden-üretim komutları için `RUNBOOK.md` §4'e bakın.

> ## ► BURADAN BAŞLAYIN (son güncelleme: 2026-07-28, Adım 26 — YARIM KALDI)
>
> ### ⏸ OTURUM BURADA DURDURULDU — devam etmek için tek iş:
> `TiltrotorIndiParams.hpp`'de **`TILT_SLEW_BOX_RATE` 1.75f → 3.00f** yap,
> `make px4_sitl_default`, sonra **`sitl-lockup-check` kriter koşusu**.
> Kanıt hazır (Adım 26c: iki koşu, ters sıra, ort. aşım %24.8 = MATLAB
> paritesi), ama kriter koşusu **yapılmadı** — tahsisatın tick başına
> otoritesini artırmak aktüatör kilitlenmesi arıza modunu yeniden
> açabilecek türden bir değişiklik, atlanmamalı. Ağaç şu an **doğrulanmış
> 1.75'te ve kaynak/ikili uyumlu.**
>
> **Asıl arıza çözüldü, ama yaw ekseni gerçek hover'da hâlâ sönümsüz.**
>
> | | Durum |
> |---|---|
> | Aktüatör kilitlenmesi (asıl bug) | ✅ **ÇÖZÜLDÜ** — Adım 11 (itki eşlemesi) + Adım 12 (`ROTOR_KM` işareti). 845 örneklik koşuda sıfır BIG_M. |
> | Dikey hız kontrolsüzlüğü | ✅ **ÇÖZÜLDÜ** — `\|vz\| ≤ 0.17 m/s` |
> | Yaw'ın sınırsız dönmesi | ✅ **ÇÖZÜLDÜ** — Adım 13 (eksen-bazlı hız limiti), iki bağımsız koşu |
> | **(Q) Yaw, düşük hızda kararsız** | ✅ **ÇÖZÜLDÜ (Adım 23 mekanizma + Adım 27 dağıtım/doğrulama).** Sebep: tahsisatın tilt slew kutusundan aç bırakılması. Kutu 1.25 → 1.75 ile kalıcı salınım yok oldu, **1.75 → 3.00 (Adım 27)** ile MATLAB paritesine ulaşıldı. **Kriterin dördü de iki bağımsız tutuş uçuşunda geçti** (yaw hata bandı −7.3…+5.9° ve −10.3…+10.3°; yaw hızı RMS 0.0014-0.0028; \|vz\| ≤1.74; irtifa RMS 0.052-0.072 m; sıfır BIG_M). ⚠️ Ayrıca Adım 27 şunu buldu: Adım 22-24'te "yaw ❌ 35-37°" diye raporlanan şey **bir kusur değil, ölçüm artefaktıydı** — araç +90° heading'de doğuyor, `yaw_sp=0` ise 90°'lik dönüş komutlamak demek. Aşağıdaki eski satırlar tarihsel: |
> | *(eski değerlendirme)* | ❌ **AÇIK — araştırmanın merkezi.** Üç uçuşluk ölçülmüş hâli: **<~2 m/s sürekli salınım, ~2 m/s marjinal, üstünde kararlı** (yaw hızı RMS ~0.4 rad/s, bant 40-80°). MATLAB aynı adımı 3.69 s'de, ζ≈0.4 ile oturtuyor — üstelik **hiç aero yaw momenti olmadan**. Yani SITL'de MATLAB'da olmayan bir kararsızlaştırıcı var. Ölçümle elenenler: gölge aktüatör modelinin tilt kanalı, `omega_dot` gecikme/gürültüsü, `dt` jitter'ı, trim ön-yükleme. Ölçülmemiş tek boşluk: **itki kanalları**. |
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

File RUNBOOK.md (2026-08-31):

# Çalıştırma Talimatları — mc_indi_tiltrotor SITL Test Kampanyası (M4-M6)

> Kurulum arka planı, mimari notlar ve bilinen açık sorunlar için → [README.md](README.md)

Bu dosya `gz_tiltrotor_indi` airframe'ini (MATLAB kontrolcüsünün PX4 C++ portu,
`~/PX4-Autopilot/src/modules/mc_indi_tiltrotor/`) SITL'de başlatıp M4-M6 test
kampanyasını çalıştırmanın adımlarını tarif eder.

---
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

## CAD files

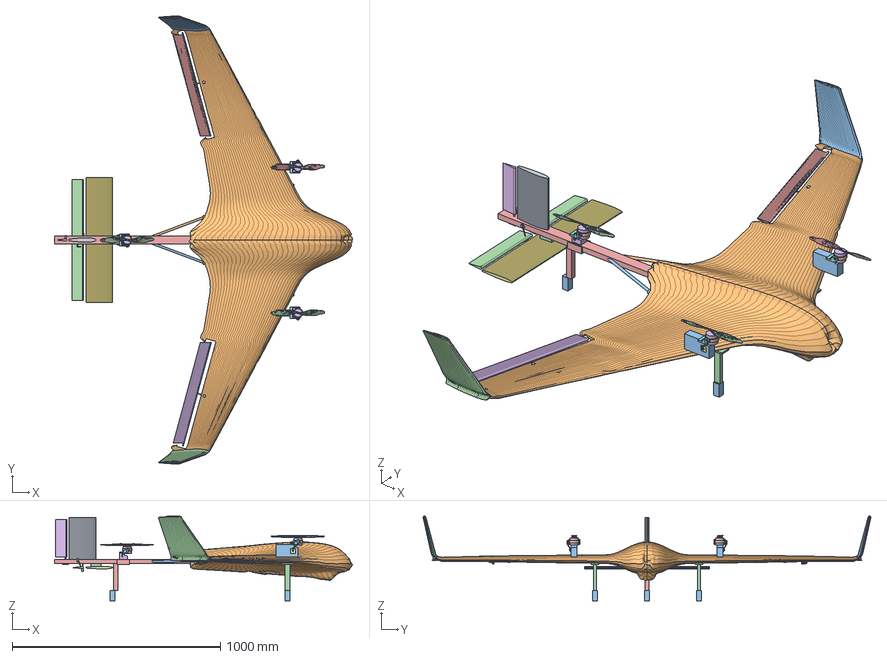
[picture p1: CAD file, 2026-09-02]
cad/step/tiltrotor_assembly.step
1432.3 x 2151.2 x 407.7 mm
boom_brace_left
boom_brace_right
elevator_left
elevator_right
elevon_left
elevon_right
hinge_pins_elevator_left
hinge_pins_elevator_right
hinge_pins_elevon_left
hinge_pins_elevon_right
hinge_pins_rudder
horn_elevator_left
horn_elevator_right
horn_elevon_left
horn_elevon_right
horn_rudder
leg_front_left
leg_front_left_strut
leg_front_right
leg_front_right_strut
leg_tail
leg_tail_strut
motor_0_right
motor_1_left
motor_2_tail
pushrod_elevator_left
pushrod_elevator_right
pushrod_elevon_left
pushrod_elevon_right
pushrod_rudder
pylon_left
pylon_right
rotor_0_right
rotor_1_left
rotor_2_tail
rudder
servo_elevator_left
servo_elevator_right
servo_elevon_left
servo_elevon_right
servo_fairing_rudder
servo_rudder
tail_boom
tail_pylon
tailplane
tailplane_strut
tilt_bearing_left_in
tilt_bearing_left_out
tilt_bearing_right_in
tilt_bearing_right_out
tilt_bearing_tail_in
tilt_bearing_tail_out
tilt_cradle_left
tilt_cradle_right
tilt_cradle_tail
tilt_crank_left
tilt_crank_right
tilt_crank_tail
tilt_horn_left
tilt_horn_right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

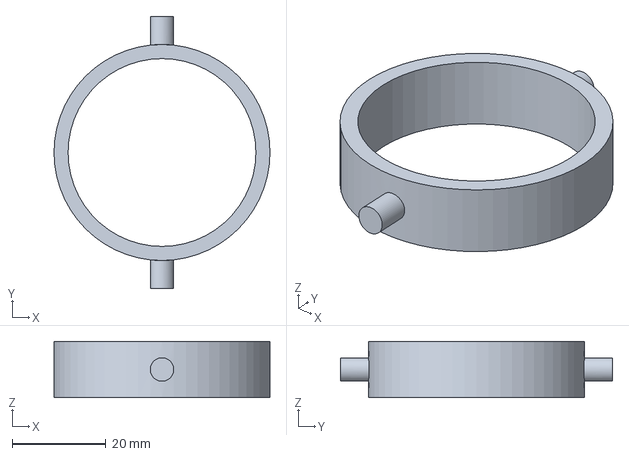
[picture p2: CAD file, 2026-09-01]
cad/step/parts/tilt_cradle_right.step
46.0 x 58.0 x 12.0 mm

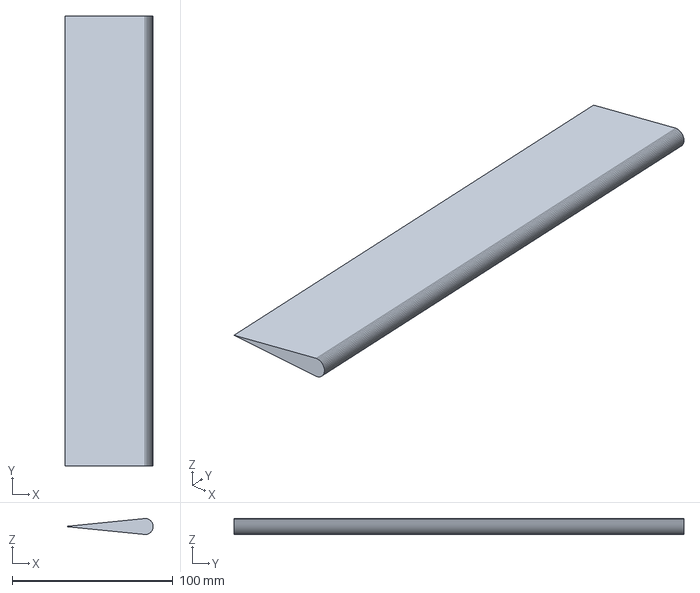
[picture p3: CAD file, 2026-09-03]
cad/step/parts_pristine/elevator_right.step
55.0 x 280.0 x 10.0 mm

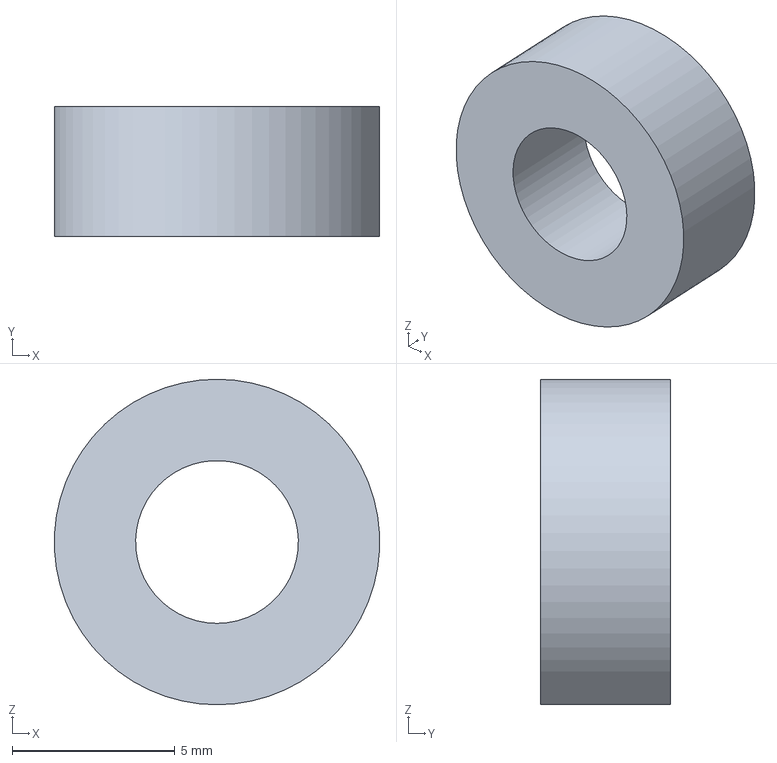
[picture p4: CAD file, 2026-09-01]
cad/step/parts/tilt_bearing_tail_out.step
9.99 x 4.00 x 10.0 mm

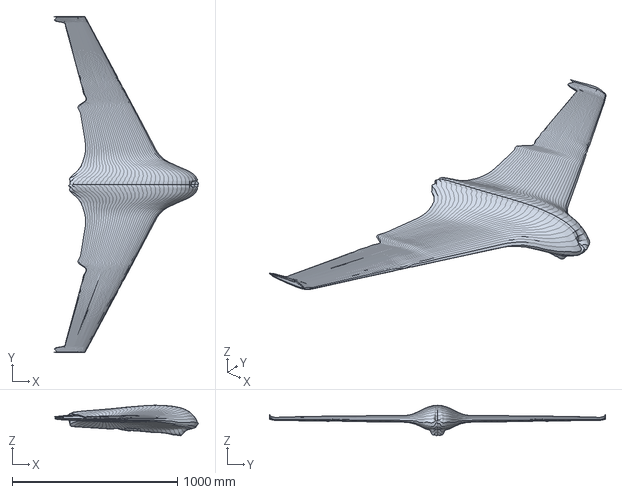
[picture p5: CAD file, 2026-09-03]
cad/step/parts_pristine/wing.step
872.0 x 2035.0 x 185.2 mm

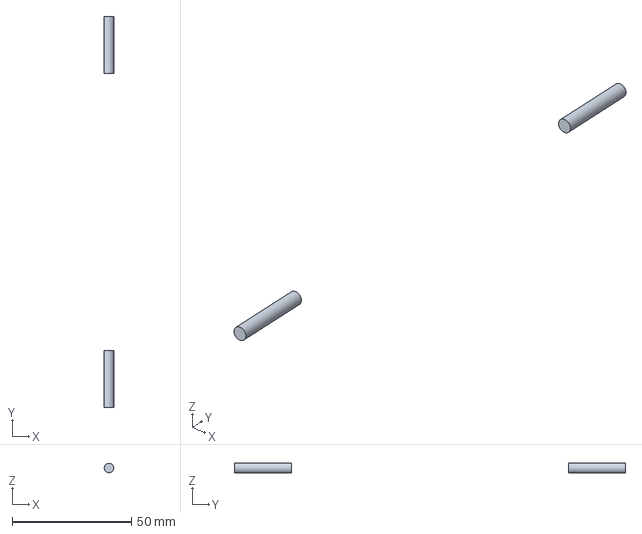
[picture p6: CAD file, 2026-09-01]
cad/step/parts/hinge_pins_elevator_left.step
4.00 x 164.0 x 4.00 mm

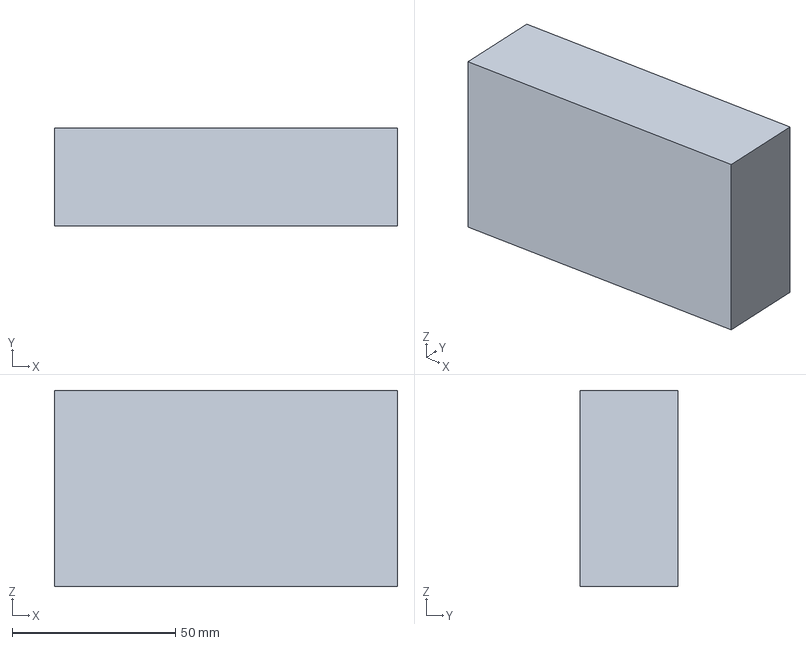
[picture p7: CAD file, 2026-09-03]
cad/step/parts_pristine/pylon_right.step
105.0 x 30.0 x 60.0 mm

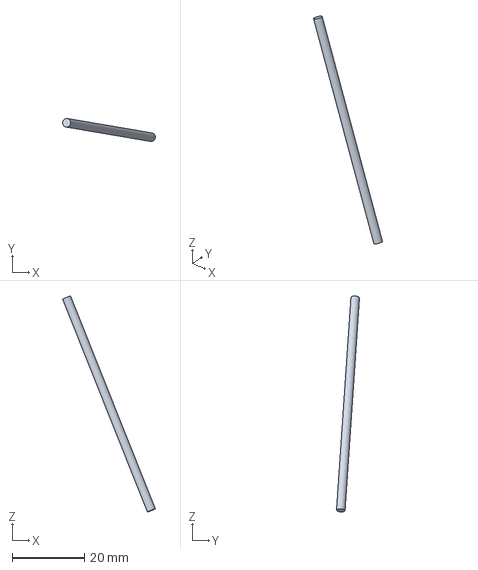
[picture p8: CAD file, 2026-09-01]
cad/step/parts/pushrod_elevator_right.step
25.7 x 6.39 x 59.9 mm

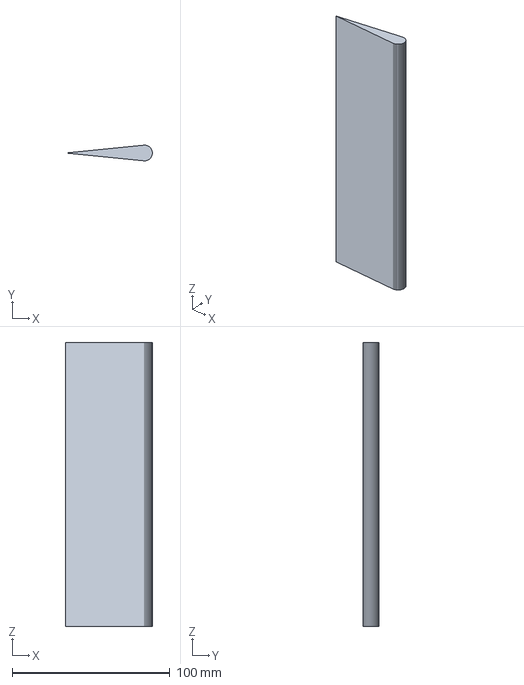
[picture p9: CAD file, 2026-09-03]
cad/step/parts_pristine/rudder.step
55.0 x 10.0 x 180.0 mm

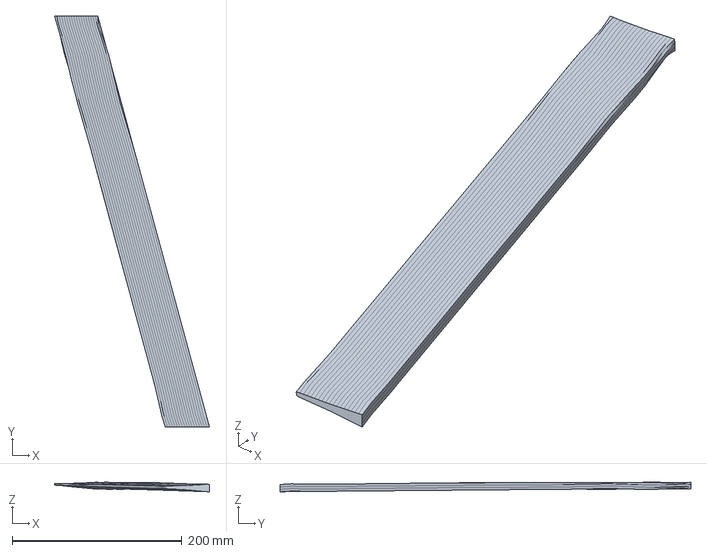
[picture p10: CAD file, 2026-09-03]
cad/step/parts_pristine/elevon_left.step
182.9 x 484.8 x 11.6 mm

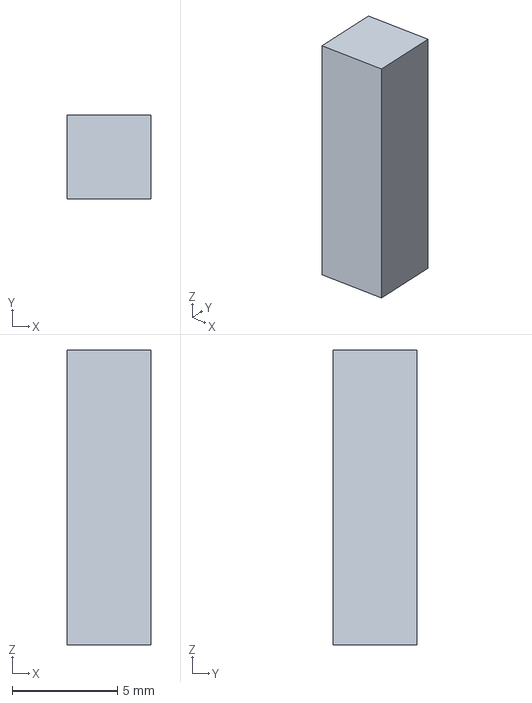
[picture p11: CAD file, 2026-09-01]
cad/step/parts/tilt_horn_left.step
4.00 x 4.00 x 14.0 mm

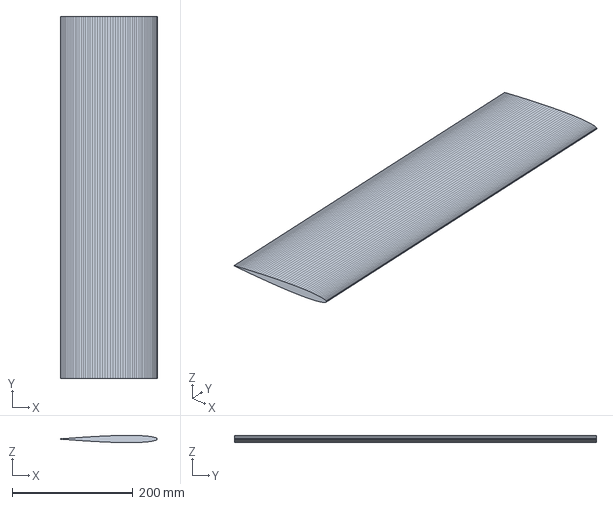
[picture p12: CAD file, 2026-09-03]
cad/step/parts_pristine/tailplane.step
160.0 x 600.0 x 12.0 mm

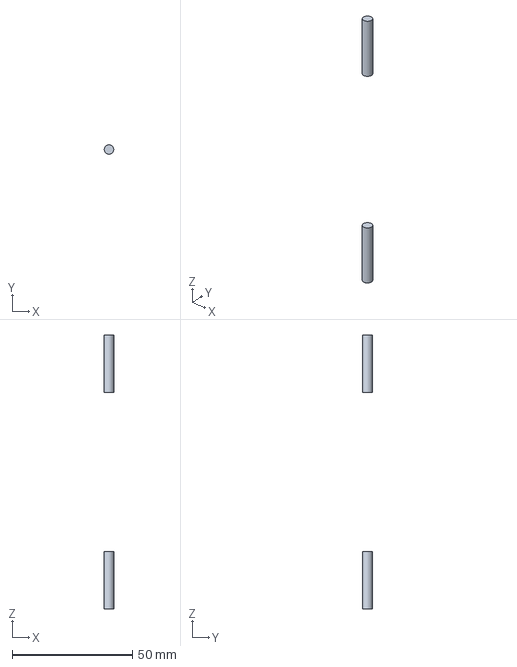
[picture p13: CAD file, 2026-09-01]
cad/step/parts/hinge_pins_rudder.step
4.00 x 4.00 x 114.0 mm

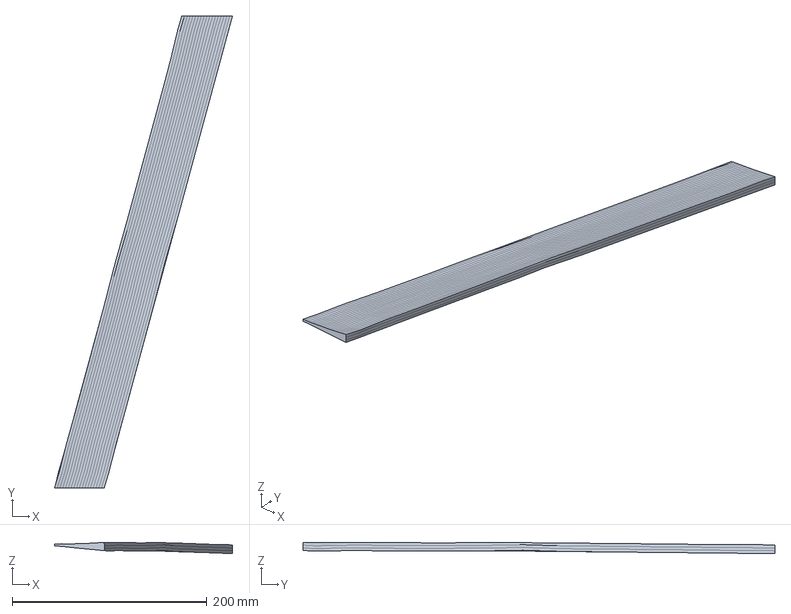
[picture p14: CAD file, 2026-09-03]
cad/step/parts_pristine/elevon_right.step
182.9 x 484.8 x 11.6 mm

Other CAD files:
cad/step/parts/elevator_right.step
cad/step/parts/pushrod_rudder.step
cad/step/parts_pristine/vertical_stabiliser.step
cad/step/parts/wing.step
cad/step/parts/boom_brace_left.step
cad/step/parts/boom_brace_right.step
cad/step/parts/elevator_left.step
cad/step/parts/elevon_left.step
cad/step/parts/elevon_right.step
cad/step/parts/hinge_pins_elevator_right.step
cad/step/parts/hinge_pins_elevon_left.step
cad/step/parts/hinge_pins_elevon_right.step
cad/step/parts/horn_elevator_left.step
cad/step/parts/horn_elevator_right.step
cad/step/parts/horn_elevon_left.step
cad/step/parts/horn_elevon_right.step
cad/step/parts/horn_rudder.step
cad/step/parts/leg_front_left.step
cad/step/parts/leg_front_left_strut.step
cad/step/parts/leg_front_right.step
cad/step/parts/leg_front_right_strut.step
cad/step/parts/leg_tail.step
cad/step/parts/leg_tail_strut.step
cad/step/parts/motor_0_right.step
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

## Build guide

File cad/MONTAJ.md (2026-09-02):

# Tilt-rotor CAD montajı — eklemler ve hareket

`step/parts/*.step` içindeki 23 parça (12 sabit + 11 hareketli) **mutlak
konumda** üretilmiştir: hepsini "orijine göre yerleştir" seçeneğiyle içe
aktarırsanız araç kendiliğinden doğru biçimde oturur. Sonrasında yalnızca eklemleri tanımlamanız yeterli.

Koordinat sistemi SDF gövde çerçevesidir: **+x burun, +y sol kanat, +z yukarı**,
başlangıç `base_link`. Birim **mm**. (SDF'teki `<model><pose>` z = 246 mm yer
ofseti uygulanmamıştır; o yalnızca aracı Gazebo zemininin üstüne kaldırır.)

## Eklem tablosu

Tümü döner (revolute) eklem. Eksen vektörleri gövde çerçevesinde birim vektördür.

| Eklem | Gövde | Menteşe noktası [mm] | Eksen | Limit | SDF adı |
|---|---|---|---|---|---|
| Sağ tilt | `motor_0_right` + `rotor_0_right` | (220, −250, 85) | (0, 1, 0) | 0° … 90° | `motor_0_joint` |
| Sol tilt | `motor_1_left` + `rotor_1_left` | (220, 250, 85) | (0, 1, 0) | 0° … 90° | `motor_1_joint` |
| Kuyruk tilt | `motor_2_tail` + `rotor_2_tail` | (−650, 0, 45) | (0, 1, 0) | **0° … 20°** | `motor_2_joint` |
| Sağ pervane | `rotor_0_right` | (220, −250, 110) | (0, 0, 1) | serbest (CCW) | `rotor_0_joint` |
| Sol pervane | `rotor_1_left` | (220, 250, 110) | (0, 0, 1) | serbest (CW) | `rotor_1_joint` |
| Kuyruk pervanesi | `rotor_2_tail` | (−650, 0, 70) | (0, 0, 1) | serbest (CCW) | `rotor_2_joint` |
| Sol elevon | `elevon_left` | (−180, 600, −5) | (−0.2619, 0.9651, 0) | ±44.7° | `left_elevon_joint` |
| Sağ elevon | `elevon_right` | (−180, −600, −5) | (0.2619, 0.9651, 0) | ±44.7° | `right_elevon_joint` |
| Sol elevatör | `elevator_left` | (−765, 150, −40) | (0, 1, 0) | ±29.8° | `left_elevator_joint` |
| Sağ elevatör | `elevator_right` | (−765, −150, −40) | (0, 1, 0) | ±29.8° | `right_elevator_joint` |
| Rudder | `rudder` | (−965, 0, 120) | (0, 0, 1) | ±29.8° | `rudder_joint` |

**Tilt ekseni +y yönündedir**, yani 0° = pervane ekseni yukarı (hover),
90° = pervane ekseni ileri (seyir). Kanat tiltleri 0…**89.95°** (SDF'te
`1.57 rad`).

⚠ **KUYRUK TİLTİ FARKLI: 0…20° (2026-08-30, adım 133).** Bu bir yazılım
tercihi değil, **fiziksel bir kısıt**: 100 mm yarıçaplı disk 90°'de alt ucu
`motor_z − 100 = −55 mm`'ye iner ve kuyruk çubuğunun İÇİNDEN geçer (ölçüldü:
`check_model_clearance.py`). Alternatif — motoru yükseltmek — denendi ve geri
alındı, çünkü `r_z` geri geçişte `τ_y = r_z·Fx − r_x·Fz` üzerinden ısırıyor ve
üç rotor da doydu (BIG_M 0 → 3843). 20°, tam görevde ölçülen en büyük kuyruk
tiltinin (2,5°) **8 katı**; o açıda çubuğa açıklık 24 mm.
Fusion'da bu limiti kurarken 90° yazmayın — montaj çakışır.

**Elevon menteşe ekseni saf y değildir.** SDF'te elevon eklemlerinde
`use_parent_model_frame` yoktur, dolayısıyla `<xyz>0 1 0</xyz>` ekseni eklemin
kendi çerçevesinde okunur ve eklemin `<pose>` künyesindeki ±0.265 rad (15.18°)
sapma açısı eksene uygulanır — menteşe, süpürülmüş firar kenarını izler.
Diğer tüm eklemlerde `use_parent_model_frame` 1'dir, eksenler doğrudan gövde
çerçevesindedir.

## Tilt gövde grupları

Tilt eklemi motoru döndürür, pervane de motorun çocuğudur. Fusion'da bunu
kurmanın en kolay yolu, önce pervaneyi motora bağlayıp sonra motoru gövdeye
bağlamaktır:

```
base_link (wing + winglet + boom + tailplane + fin + pylon + strut
           + 3 inis ayagi, sabit)
└── motor_0_right      ← tilt eklemi, (220, −250, 85), y ekseni, 0…90°
    └── rotor_0_right  ← döner eklem, (220, −250, 110), z ekseni, serbest
```

Sol grup aynıdır. **Kuyruk grubu limit bakımından farklıdır: 0…20°**
(yukarıdaki uyarı).

## Fusion 360

1. `Insert > Insert McMaster / Upload` yerine **File > Open** ile
   `step/tiltrotor_assembly.step` — **23 gövde** tek montaj olarak gelir.
   Alternatif: `step/parts/*.step` dosyalarını tek tek `Insert > Insert Derive`.
2. Gövde eklemleri (kanat, winglet, boom, tailplane, fin, pylon, strut,
   **3 iniş ayağı**) için **Rigid Group** oluşturun. Bunların hiçbiri hareketli
   değildir; yalnızca hareketli 11 parça (3 motor + 3 pervane + 5 yüzey) eklem
   alır.
3. Her hareketli parça için `Assemble > Joint > Revolute`:
   - `Motion > Rotate` eksenini yukarıdaki tabloya göre seçin,
   - eklem konumunu tabloda verilen noktaya taşıyın (Joint origin > Between two
     faces yerine `Offset` alanlarına mm değerlerini yazmak en hızlısı),
   - `Joint Limits` altına min/max açıyı girin.
4. Tilt hareketini görmek için eklemi sağ tıklayıp **Drive Joints**.

## SolidWorks

1. `File > Open > tiltrotor_assembly.step`, "Import as **assembly**" seçin
   (multibody part değil — o hâlde eklem tanımlayamazsınız).
2. Gövde parçalarını **Fix** yapın.
3. Hareketli parçalara `Mate > Mechanical > Hinge` veya eksenel `Concentric` +
   `Coincident` çifti; eksen için tablo değerlerine göre bir **Reference Axis**
   oluşturun (`Features > Reference Geometry > Axis`).
4. Açı sınırları için `Advanced Mates > Angle` mate'ine min/max girin.

## Doğrulama

`onizleme.png` üç görünüşü gösterir. Ana ölçüler:

| Ölçü | CAD | SDF/mesh kaynağı |
|---|---|---|
| Kanat açıklığı (winglet dahil) | 2157 mm | mesh zarfı 2151 mm |
| Kanat açıklığı (winglet hariç) | 2035 mm | — |
| Kök kirişi (y=0 kesiti) | 776 mm | mesh kesiti 776 mm |
| Kanat gövdesi x uzanımı | 872 mm | süpürme dahil |
| Toplam uzunluk | 1387 mm | burun +530, rudder firar −855 |
| Pervane çapı | 259 mm | mesh 258.8 mm — SDF collision da bu değere düzeltildi (adım 142) |
| Tilt rotor istasyonu | x=220, y=±250 | SDF `motor_0/1` pose |
| Elevon açıklığı (her biri) | 485 mm | `x8_elevon_*.dae` |
| **Kuyruk çubuğu uzanımı** | **−990 … −190 mm** | 2026-08-31, fin'i tam destekler |
| **Fin (dikey stab.) x** | **−980 … −820 mm** | fin çubuğun ÜZERİNDE oturur |
| **Rudder x** | **−1015 … −960 mm** | fin ile birlikte geriye alındı |
| **Ön pilon x** | **165 … 270 mm** | öne uzanan kol (adım 143) |
| **Ön motor konumu** | **x=270, y=±350 mm** | nasel hücum kenarının önünde |
| **İniş ayağı ucu z** | **−200 mm** | gövde alt yüzünden 40 mm aşağıda |

## 2026-08-31 geometri güncellemesi

Bu CAD, `tiltrotor_tailplane_model.sdf`'in **31 Ağustos 2026 hâlinden**
üretilmiştir. Önceki sürümden farkları — hepsi ölçülmüş bir çakışmayı çözer
(`check_model_clearance.py`, rapor Adım 132-139):

| parça | önce | sonra | neden |
|---|---|---|---|
| ön pilonlar | 50 mm boy, x=220 | **30 mm, x=205** | tam tiltte (90°, seyir duruşu) disk KENDİ pilonunu süpürüyordu |
| fin | x=−740 | **x=−900** | disk tilt=0'da, yani hover boyunca fininin içinden geçiyordu |
| rudder | x=−830 | **x=−990** | fin ile birlikte (menteşe havada kalmasın) |
| kuyruk çubuğu | 620 mm, 40 mm kalın | **800 mm, 20 mm** | fin desteklensin + disk çubuğu kesmesin |
| kuyruk tilt limiti | 0…90° | **0…20°** | fiziksel kısıt, yukarıdaki uyarı |
| iniş takımı | **yoktu** | **3 ayak** | araç gövde levhasıyla yere oturuyordu |
| **ön motorlar** | x=220, y=±250 | **x=270, y=±350** | disk kanadın gövde podunun içinden geçiyordu (adım 143) |
| **ön pilonlar** | 30 mm kutu, x=205 | **105 mm kol, x=217,5** | motor artık hücum kenarının önünde, pilon öne uzanıyor |

**Çakışma durumu: 5 → 0.** En dar açıklık 24,2 mm (kuyruk çubuğu, tilt 20°).
Ön rotorlar `cad/dogrula.py` katı denetiminde **ilk kez tüm tilt açılarında temiz**
(0°–90°); mesh açıklığı 32,8 mm.

⚠ **PERVANE YARIÇAPI DÜZELTİLDİ (adım 142).** SDF'in rotor collision silindiri
100 mm yarıçapındaydı, oysa gerçek pervane mesh'i (`iris_prop_*.dae`)
**129,4 mm**. Yani disk fiziksel olarak olduğundan küçük görünüyordu ve
`check_model_clearance.py` SDF'ten okuduğu için aynı hatayı tekrarlıyordu —
yapılan her açıklık ölçümü **29 mm iyimserdi**. Bunu `cad/dogrula.py` mesh'ten
ölçüp yakaladı; fin bu yüzden −860'tan −900'e alındı.

⚠ Kuyruk motoru z=45 mm'de KALDI. Bir ara 135 mm'ye yükseltilmişti (9 cm
pilon) ve **geri alındı**: `r_z` geri geçişte kontrol otoritesini bozuyordu.
Eski bir CAD sürümünde o pilonu görürseniz, güncel olan bu değildir.

## Adım 143 — ön naseller hücum kenarının önüne alındı (31 Ağustos 2026)

Ön motorlar **x=220 → 270 mm, y=±250 → ±350 mm** taşındı; pilon 30 mm'lik bir
kutudan **105 mm'lik öne uzanan bir kola** dönüştü. Motor artık kanadın hücum
kenarının (o istasyonda x=+202 mm) **68 mm önünde** duruyor — gerçek
tiltrotorların nasel düzeni. `r_z` (motor z=85 mm) **değişmedi**.

### Neden zorunluydu

Pervane diski, kanadın **gövde podunun** içinden geçiyordu. İki ayrı ölçüm
hatası bunu uzun süre gizledi:

1. **SDF'in collision kutusu kanadı temsil etmiyor.** Kutu `0,55 × 2,144 ×
   0,05` m ve yalnızca `z = −160…−110 mm` aralığında; gerçek mesh ise
   `z = −100…+208 mm`. Pod (yarım genişlik 200 mm, x=+288 mm'ye kadar öne
   uzanıyor) kutuda **hiç yok**. Kutuya bakan her ölçüm 65 mm açıklık
   raporluyordu, gerçek 0 mm'ken.
2. **Mesh'in köşelerine bakmak da yetmiyor.** İlk mesh kontrolü köşe
   noktalarına uzaklık ölçüyordu; bu mesh'te köşe aralığı ~21 mm, disk yüzeye
   köşeler arasından girdiğinde ölçüm "32,8 mm temiz" diyordu. `cad/dogrula.py`
   gerçek katı boolean'ı yaptığı için baştan beri nüfuz raporluyordu ve **haklıydı**.

`check_model_clearance.py` artık üçgenleri alanla orantılı örnekliyor (~1,5 mm
yoğunluk) ve diskin 10,6 mm kalınlığını hesaba katıyor. Eski konumu ⛔ olarak
yakaladığı bir regresyon sınamasıyla doğrulandı.

### Neden başka çözüm yok

90°'de disk **dikey bir düzlem**. Göbek yerel hücum kenarının gerisindeyse
kanadın kirişini keser. Süpürme yüzünden dışa gitmek x'i geriye zorlar, bu
yüzden pilon kanadın üstünde kaldığı sürece **açıklık boyunca hiçbir istasyon
çalışmıyor** (y=350…700 mm'nin tamamında 0,0 mm).

| seçenek | sonuç |
|---|---|
| Pervaneyi küçült | **işe yaramıyor** — 170 mm çapta bile 0,0 mm; sorun diskin yarıçapı değil *düzlemi* |
| Açıklıkta dışa al | **işe yaramıyor** — süpürme x'i geriye zorluyor |
| Tilt'i sınırla | **ölü** — sabit kanat 90° gerektiriyor (55°'de temizleniyor) |
| Pilonu yükselt | çalışır ama **+80 mm** gerekir; `r_z`'yi değiştirir, ki bu Adım 132'de geri geçişi bozan büyüklüğün ta kendisi |
| **Naseli öne al** | **seçildi** — 32,8 mm, `r_z` sabit |

### Kontrol bedeli

`arm_ratio = 2·ROTOR_PX[0]/|ROTOR_PX[2]|` 0,677 → **0,831**. Hover bölüşümü
buna göre kayıyor; `TiltrotorIndiControl.hpp` içinde otomatik türetiliyor,
elle güncellenecek ayrı bir sabit yok. Kuyruk kolu ve `r_z` değişmedi.

## Adım 154 — kuyruk kolu, fin ve strut (31 Ağustos 2026)

CAD, SDF'in Adım 154 hâline eşitlendi. Değişenler:

| parça | önce | sonra | neden |
|---|---|---|---|
| kuyruk motoru/rotoru | x=−650 | **x=−550** | kuyruk trim payı %29 → %33; iniş sıçramasında kuyruk 0 N'e dayanıyordu |
| fin | x=−900, z=120 | **x=−780, z=100** | öne alındı (kullanıcı kararı); z indirildi çünkü **20 mm havada asılıydı** |
| rudder | x=−990, z=120 | **x=−870, z=100** | fin ile birlikte |
| çubuk | 800 mm, merkez −590 | **710 mm, merkez −545** | fin öne gelince arka uzantı gereksizleşti |
| tailplane strut | z merkez −15, boy 60 | **z merkez −22,5, boy 45** | üst yüzü çubuğun 15 mm üstüne taşıyordu; fin inince **4,9 cm³ girişim** oluştu |

**Strut girişimini `cad/dogrula.py` yakaladı**, SDF denetimleri değil. Strut'un
tek işi tailplane'i çubuğa bağlamak; çubuğun üstüne taşmasının işlevi yoktu.
Üst yüzü çubuğun üst yüzüyle (z=0,000) hizalandı.

**Fin neden 20 mm havadaydı:** bütün açıklık denetimleri **çakışma** arıyordu,
hiçbiri **boşluk** aramıyordu. Artık `check_model_clearance.py` içindeki
`connectivity_audit()` köke ulaşılabilirlik arıyor.

Doğrulama: **61 geçti, 0 CAD hatası**, MATLAB 8/8, tam otonom görev SITL'de
10 evrenin 10'u (157 s).

---

## İmalat kısıtı — elevatör yukarı sapması (1 Eylül 2026)

**Fiziksel araçta elevatörler +26°'yi geçmemeli.** Yazılım tarafında bir
değişiklik yok ve olmayacak; bu bir montaj/imalat notudur.

Her iki elevatörün **iç-arka köşesi**, yukarı sapmada kuyruk çubuğunun altına
giriyor. Elevatör `y = 10…290` arasında, çubuk ise `y = ±20` — yani plandan
bakıldığında elevatörün en içteki 10 mm'lik şeridi çubuğun altında kalıyor.
Menteşe `x = −765`'te; köşe `x ≈ −808`, yani menteşenin 43 mm arkasında.
Sapma açısı büyüdükçe bu köşe yükseliyor ve çubuğun alt yüzeyine (`z = −20`)
dayanıyor.

| sapma | girişim | en derin nokta |
|---|---|---|
| ≤ +26° | yok | — |
| +27° | 0,037 cm³ | 2,7 mm |
| +28° | 0,057 cm³ | 3,5 mm |
| **+29,8° (SDF/kod limiti)** | **0,098 cm³** | **4,8 mm** |

Aşağı sapmada (−29,8°) temiz — köşe çubuktan uzaklaşıyor. İki elevatör birebir
simetrik. Girişim kutusu: `x −808…−798, y 10…20, z −20…−15,2`.

### Neden yazılım tarafına dokunulmadı

`SURF_MAX[2..4] = 0.52f` (`TiltrotorIndiParams.hpp:80`) ile SDF'teki
`<upper>0.52</upper>` birbirine eşit ve doğru. Simülasyonda bu girişimin hiçbir
etkisi yok: **elevatör link'lerinde `<collision>` elemanı yok** ve bütün
link'lerde `<self_collide>0</self_collide>`. Aerodinamik lift/drag
eklentisinden, eklem açısından geliyor — temastan değil. Dolayısıyla SITL,
MATLAB ve HITL sonuçlarının hiçbiri bu bulgudan etkilenmiyor.

Limiti 26°'ye indirmek pitch otoritesini %13 kesiyordu; elevatörün iç kenarını
12 mm kısaltmak (`y=10` → `y=22`) girişimi tamamen kaldırıyordu ama aero panel
alanını %4 küçültüp SITL doğrulaması gerektiriyordu. **Üçüncü yol seçildi:**
geometri ve sabitler aynen bırakıldı, kısıt montaj notu olarak kayda geçti.

### Montajda ne yapılacak — iki yoldan biri

1. **Mekanik durdurucu:** elevatör servo bağlantısına yukarı yönde duran
   fiziksel stop konur. Tercih edilen yol; parça geometrisi SDF ile birebir
   kalır.

   ⚠ **DÜZELTME (1 Eylül 2026): +26° iyimser.** Katı gövde üzerinde 1°
   adımlarla ölçüldüğünde elevatör kuyruk çubuğuna **+24°'de değmeye
   başlıyor** (+22° son tam temiz açı); +26°'de girişim 0,020 cm³, +29,8°'de
   0,098 cm³. Yani +26°'lik durdurucu 0,02 cm³'lük bir temasa izin veriyor.
   **Temiz sınır ~+23°.** Ölçüm `cad/dogrula_mekanizma.py` [3] denetiminde
   yeniden üretilebilir; kapı bu kısıtı `temiz sinir ~+-25 deg` olarak
   raporlar (25 adımlık taramanın çözünürlüğü).
2. **Kenar kısaltma:** elevatörün iç kenarı 12 mm kısaltılır (`y=10` → `y=22`).
   Açıklığın %4'ü; bu yapılırsa **CAD artık SDF ile birebir olmaz** ve
   `dogrula.py` kapsam denetimi ölçü sapması verir — o yüzden ancak SDF de
   güncellenirse yapılmalı.

### Bulgu nasıl çıktı

Eski `check_surface_sweep` mutlak hacim eşiği (0,2 cm³) kullanıyordu; bu
girişim 0,098 cm³ olduğu için **eşiğin altında kalıp görünmüyordu**. Test
ortalama film kalınlığına geçirilince (`FILM_TOL = 0,05 mm`) ortaya çıktı:
hacmi küçük ama film 0,90 mm, yani lokalize gerçek bir saplanma. Aynı
değişiklik, elevonların kanatla paylaştığı loft yüzeyinden gelen üç sahte
uyarıyı da düşürdü (film 0,011 mm).

---

# Montajda karar verilecekler

Mekanizma çalışmasından (1 Eylül 2026) çıkan ve **imalata başlamadan önce
karara bağlanması gereken** maddeler. Ayrıntılı ölçümler ve denenip elenen
yollar için `cad/MEKANIZMA_GUNLUGU.md`.

### K1 — Elevatör mekanik durdurucu açısı
Ölçüm temasın **+24°'de** başladığını söylüyor (+22° son tam temiz açı).
Yukarıdaki eski not +26° diyor ve o açı 0,020 cm³ girişime izin veriyor.
**Karar:** durdurucu +23°'ye mi çekilecek, yoksa +26°'de kalıp o teması
kabul mü edilecek? Kontrol tarafı `model.sdf`'teki ±29,8° limitiyle
çalışmaya devam eder; bu yalnızca fiziksel stop.

### K2 — Kuyruk menteşe hattındaki 11 mm boşluk
Elevatör↔tailplane ve rudder↔fin arasında 11,0 mm boşluk var (elevon tarafı
0,2 mm ile doğru). CAD'de çözümün reçetesi günlükte yazılı ama uygulanmadı.
**Karar:** (a) CAD'de düzeltilsin mi, yoksa (b) montajda dolgu/conta ile mi
kapatılacak? (b) seçilirse menteşe hattı aerodinamik olarak sızdırır.

### K3 — Winglet'lerin kanada bağlanması
Winglet'ler kanatla tek gövdeye kaynatılmadı; tabanları kanat ucunun 5 mm
içine oturur ama ayrı katı kalır (OCC'de birleştirme kararsız).
**Karar:** montajda `Rigid Group` mu yapılacak, yapıştırma/lamine mi, yoksa
CAD'de birleştirme yeniden mi denenecek?

### K4 — Servo seçimi
Kuyruk yüzeyleri 22 mm'lik standart servoyu **almıyor** (tailplane 9,9 mm,
fin 16,5 mm). Tasarımda elevatör ve rudder servoları kuyruk çubuğuna
gömüldü, rudder için boom altına küçük bir karina eklendi.
**Karar:** bu düzen kabul mü, yoksa 6-9 mm'lik ince kanat servosu mu
kullanılacak? Karina dış hat değişikliğidir.

### K5 — Yatak seçimi
Tilt eksenlerinde **MR105ZZ** (Ø5 × Ø10 × 4) varsayıldı; çatal yuvaları ve
kızak mil uçları bu ölçüye göre. **Karar:** bu yatak temin edilecek mi,
yoksa ölçü başka bir yatağa mı uyarlanacak?

### K6 — Pervane dış palasının kalınlaştırılması
`iris_prop_cw.dae` görsel mesh'i dış palada 0,2 mm'ye iniyordu; imal
edilebilirlik için asgari kesit kalınlığı **1,2 mm**'ye çıkarıldı (pervane
hacmi 4,61 → 7,57 cm³). Bu **sim geometrisinden bilinçli bir sapmadır**.
**Karar:** 1,2 mm yeterli mi, malzemeye göre artırılacak mı?

### K7 — Elevon asimetrisi
Sağ ve sol elevon birbirinin aynası değil (açıklıkta 8,0 mm fark).
**Karar:** ikisi farklı parça olarak mı üretilecek, yoksa CAD'de aynalanıp
tek kalıba mı indirilecek? İkincisi `dogrula.py` kapsam denetiminde ölçü
sapması verir.

### K8 — Kuyruk çubuğu desteği
Boom gövdeye yalnızca ~56 mm giriyordu; V-destek eklenerek konsol ~630 mm
→ ~370 mm'ye indirildi. **Karar:** destek çubukları karbon boru mu, baskı
parça mı? Kanat ve boom bağlantı göbekleri buna göre boyutlanmalı.

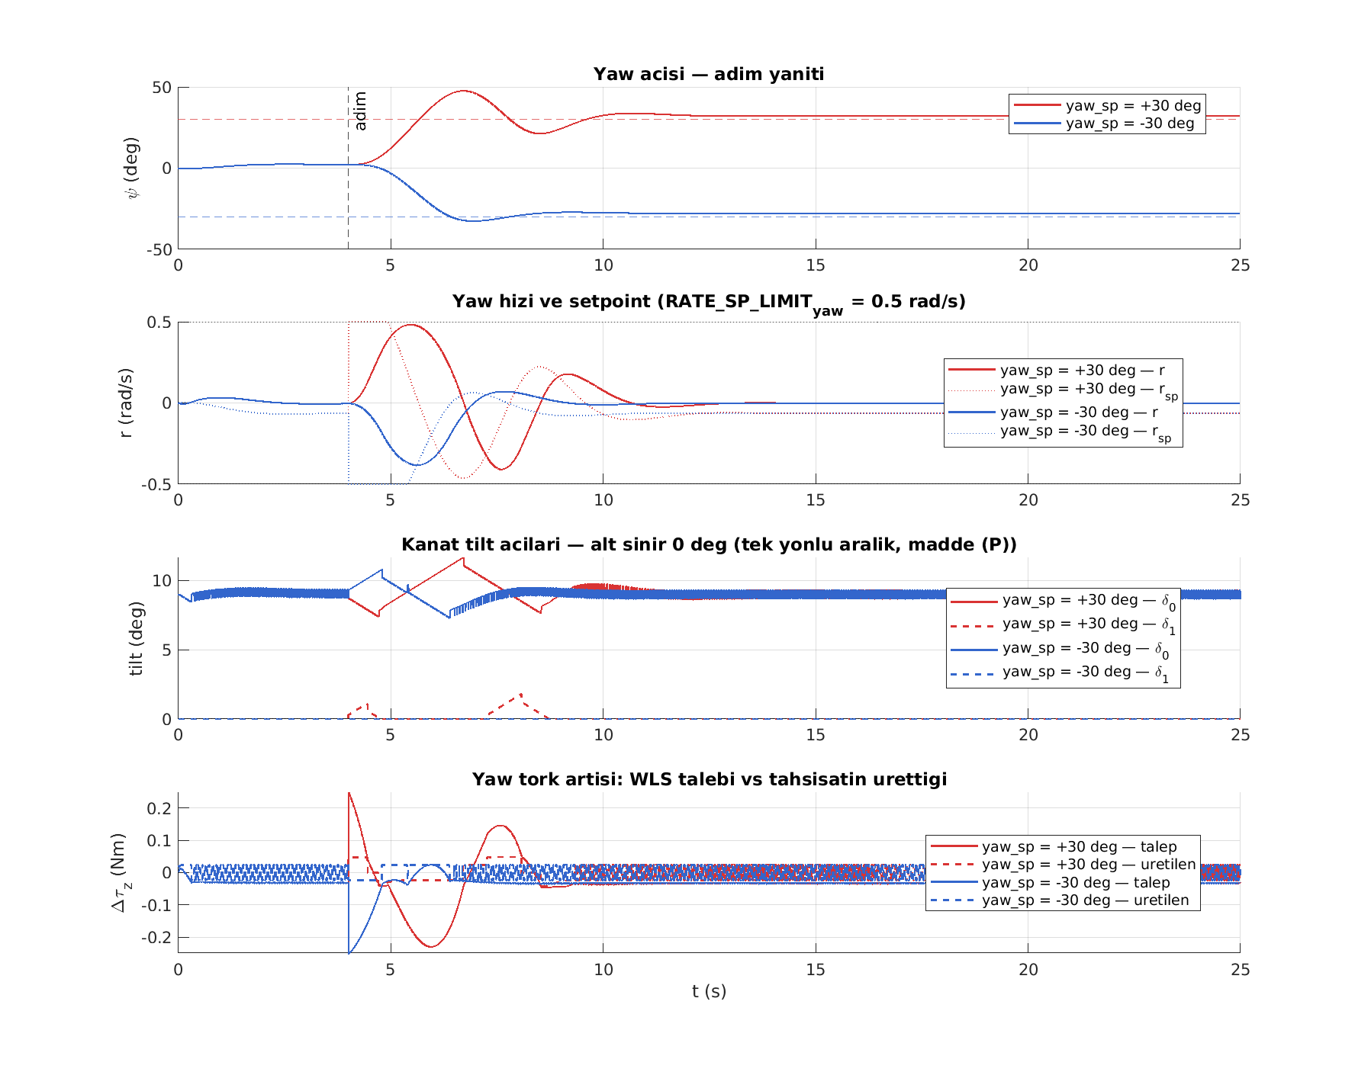
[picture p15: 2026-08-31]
yaw_step_test_rate2.0.png

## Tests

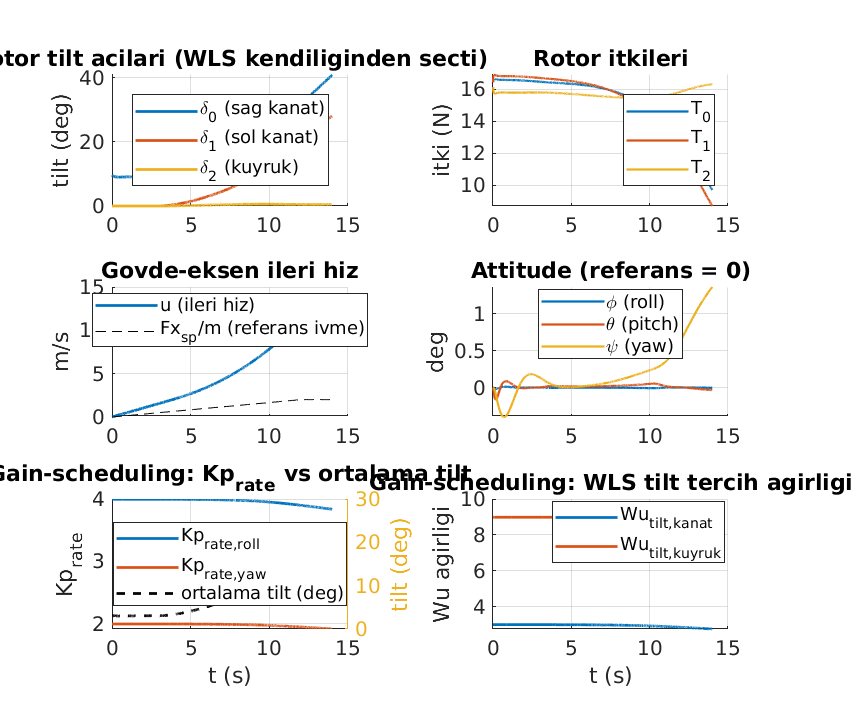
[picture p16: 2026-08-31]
transition_test.png

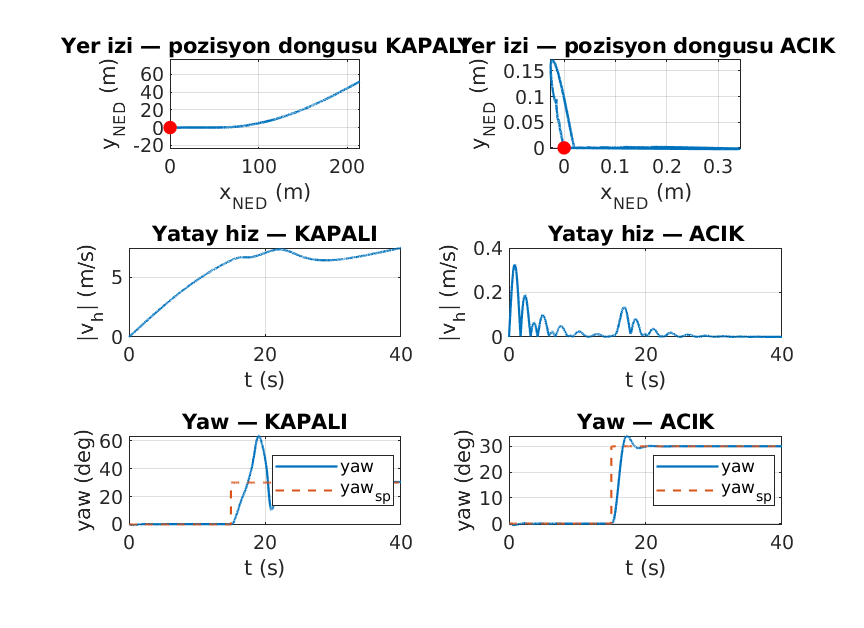
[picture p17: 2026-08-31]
station_keeping_test.png

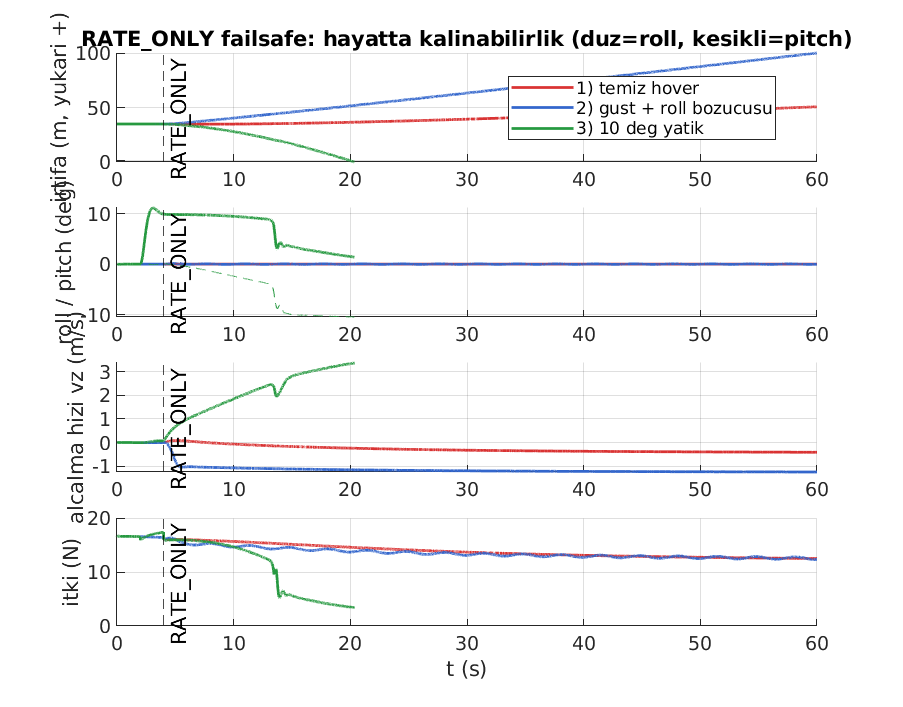
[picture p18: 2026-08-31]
rate_only_test.png

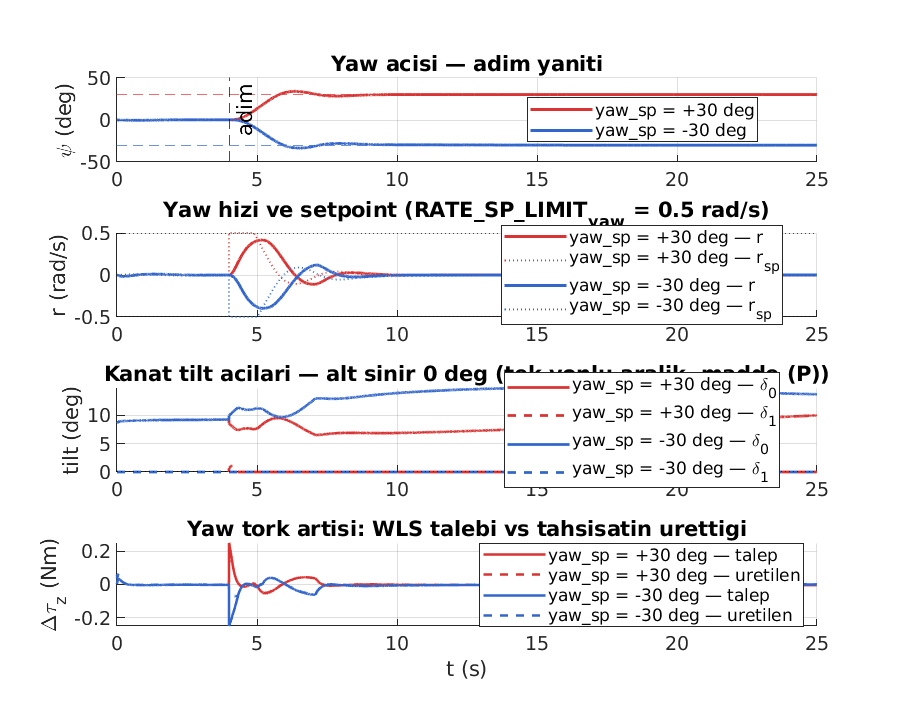
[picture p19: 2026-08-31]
yaw_step_test.png

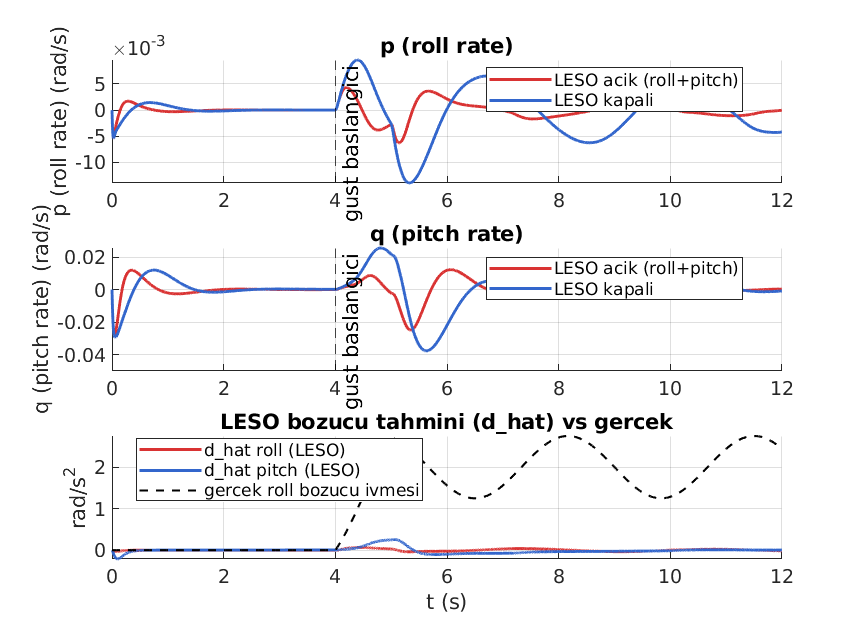
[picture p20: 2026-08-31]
hover_gust_test.png

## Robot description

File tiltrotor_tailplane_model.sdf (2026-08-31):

<?xml version="1.0" encoding="UTF-8"?>
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
<sdf version='1.5'>
  <model name='tiltrotor_tailplane'>
    <pose>0 0 0.246 0 0 0</pose>
    <link name='base_link'>
      <pose>0 0 0 0 0 0</pose>
      <inertial>
        <pose>0 0 0 0 0 0</pose>
        <mass>5</mass>
        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
        <inertia>
          <ixx>0.2</ixx>
          <ixy>0</ixy>
          <ixz>0</ixz>
          <iyy>0.25</iyy>
          <iyz>0</iyz>
          <izz>0.25</izz>
        </inertia>
      </inertial>
        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
        <enable_wind>true</enable_wind>
      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
      <gravity>1</gravity>
      <velocity_decay />
      <self_collide>0</self_collide>

      <sensor name="imu_sensor" type="imu">
        <gz_frame_id>base_link</gz_frame_id>
        <always_on>1</always_on>
        <update_rate>250</update_rate>
        <imu>
          <angular_velocity>
            <x>
              <noise type="gaussian">
                <mean>0</mean>
                <stddev>0.0003394</stddev>
                <dynamic_bias_stddev>3.8785e-05</dynamic_bias_stddev>
                <dynamic_bias_correlation_time>1000</dynamic_bias_correlation_time>
              </noise>
            </x>
            <y>
              <noise type="gaussian">
                <mean>0</mean>
                <stddev>0.0003394</stddev>
                <dynamic_bias_stddev>3.8785e-05</dynamic_bias_stddev>
                <dynamic_bias_correlation_time>1000</dynamic_bias_correlation_time>
              </noise>
            </y>
            <z>
              <noise type="gaussian">
                <mean>0</mean>
                <stddev>0.0003394</stddev>
                <dynamic_bias_stddev>3.8785e-05</dynamic_bias_stddev>
                <dynamic_bias_correlation_time>1000</dynamic_bias_correlation_time>
              </noise>
            </z>
          </angular_velocity>
          <linear_acceleration>
            <x>
              <noise type="gaussian">
                <mean>0</mean>
                <stddev>0.004</stddev>
                <dynamic_bias_stddev>0.006</dynamic_bias_stddev>
                <dynamic_bias_correlation_time>300</dynamic_bias_correlation_time>
              </noise>
            </x>
            <y>
              <noise type="gaussian">
                <mean>0</mean>
                <stddev>0.004</stddev>
                <dynamic_bias_stddev>0.006</dynamic_bias_stddev>
                <dynamic_bias_correlation_time>300</dynamic_bias_correlation_time>
              </noise>
            </y>
            <z>
              <noise type="gaussian">
                <mean>0</mean>
                <stddev>0.004</stddev>
                <dynamic_bias_stddev>0.006</dynamic_bias_stddev>
                <dynamic_bias_correlation_time>300</dynamic_bias_correlation_time>
              </noise>
            </z>
          </linear_acceleration>
        </imu>
      </sensor>
      <sensor name="air_pressure_sensor" type="air_pressure">
        <gz_frame_id>base_link</gz_frame_id>
        <always_on>1</always_on>
        <update_rate>50</update_rate>
        <air_pressure>
          <pressure>
            <noise type="gaussian">
              <mean>0</mean>
              <stddev>0.01</stddev>
            </noise>
          </pressure>
        </air_pressure>
      </sensor>
      <sensor name="magnetometer_sensor" type="magnetometer">
        <gz_frame_id>base_link</gz_frame_id>
        <always_on>1</always_on>
        <update_rate>100</update_rate>
        <magnetometer>
          <x>
            <noise type="gaussian">
              <stddev>0.0001</stddev>
            </noise>
          </x>
          <y>
            <noise type="gaussian">
              <stddev>0.0001</stddev>
            </noise>
          </y>
          <z>
            <noise type="gaussian">
              <stddev>0.0001</stddev>
            </noise>
          </z>
        </magnetometer>
      </sensor>
      <sensor name="navsat_sensor" type="navsat">
        <gz_frame_id>base_link</gz_frame_id>
        <always_on>1</always_on>
        <update_rate>30</update_rate>
      </sensor>
    </link>

    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
    <link name='motor_0'>
      <pose>0.27 -0.35 0.085 0 0 0</pose>
      <inertial>
        <pose>0 0 0 0 0 0</pose>
        <mass>0.05</mass>
        <inertia>
          <ixx>0.0166704</ixx>
          <ixy>0</ixy>
          <ixz>0</ixz>
          <iyy>0.0166704</iyy>
          <iyz>0</iyz>
          <izz>0.0167604</izz>
        </inertia>
      </inertial>
        <enable_wind>true</enable_wind>
      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
      <gravity>1</gravity>
      <velocity_decay />
      <self_collide>0</self_collide>
    </link>
    <joint name='motor_0_joint' type='revolute'>
      <child>motor_0</child>
      <parent>base_link</parent>
      <axis>
        <xyz>0 1 0</xyz>
        <limit>
          <lower>0.</lower>
          <upper>1.57</upper>
        </limit>
        <dynamics>
          <friction>1.0</friction>
          <spring_reference>0</spring_reference>
          <spring_stiffness>0</spring_stiffness>
        </dynamics>
        <use_parent_model_frame>1</use_parent_model_frame>
      </axis>
    </joint>
    <link name='rotor_0'>
      <pose>0.27 -0.35 0.11 0 0 0</pose>
      <inertial>
        <pose>0 0 0 0 0 0</pose>
        <mass>0.005</mass>
        <inertia>
          <ixx>9.75e-07</ixx>
          <ixy>0</ixy>
          <ixz>0</ixz>
          <iyy>0.000166704</iyy>
          <iyz>0</iyz>
          <izz>0.000167604</izz>
        </inertia>
      </inertial>
        <enable_wind>true</enable_wind>
      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
      <gravity>1</gravity>
      <velocity_decay />
      <self_collide>0</self_collide>
    </link>
    <joint name='rotor_0_joint' type='revolute'>
      <child>rotor_0</child>
      <parent>motor_0</parent>
      <axis>
        <xyz>0 0 1</xyz>
        <limit>
          <lower>-1e+16</lower>
          <upper>1e+16</upper>
        </limit>
        <dynamics>
          <spring_reference>0</spring_reference>
          <spring_stiffness>0</spring_stiffness>
        </dynamics>
        <use_parent_model_frame>1</use_parent_model_frame>
      </axis>
    </joint>
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

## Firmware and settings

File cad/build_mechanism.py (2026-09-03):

#!/usr/bin/env python3
"""Mekanizma parçalarını üretir: tilt grubu, iniş takımı bağlantısı, kumanda
yüzeyi menteşe/tahrik donanımı, kuyruk çubuğu desteği.

Kaynak  : model.sdf (menteşe eksenleri)
          + cad/step/parts_pristine/*.step  (bu betiğin değiştirdiği gövdeler)
          + cad/step/parts/*.step           (yalnız ölçülen gövdeler: çubuk, bacaklar)
Çıktı   : cad/step/parts/*.step  (yeni parçalar + menteşe boşluğu açılmış ana gövdeler)

Girdi ve çıktı AYRI dizinlerdedir; betik bu yüzden istenildiği kadar tekrar
koşulabilir (bkz. TURETILEN).

NEDEN AYRI BİR BETİK: build_tiltrotor_cad.py aerodinamik gövdeleri `.dae`
mesh'lerinden loft eder ve mesh dizini olmadan koşamaz. Buradaki parçaların
hiçbiri mesh'e ihtiyaç duymaz — hepsi SDF'ten türeyen eksenler etrafında kutu
ve silindirdir, menteşe boşlukları da mevcut STEP gövdelerinden kesilir.
Böylece mesh'siz bir makinede de mekanizma yeniden üretilebilir.

MENTEŞE SAYILARI BURAYA YAZILMAZ. fusion_02_joints.py'nin ayrıştırıcısı
ödünç alınır; bu deponun aynı sayıyı birden çok yerde tutmaktan gördüğü
zarar için bkz. cad/README.md. Buradaki sabitler yalnızca TASARIM
seçimleridir (yatak ölçüsü, plaka kalınlığı, servo gövdesi) — SDF'te
karşılığı olan hiçbir değer tekrarlanmaz.

Koordinatlar SDF gövde çerçevesi, mm: +x burun, +y sol kanat, +z yukarı.
"""
import os
import re
import sys
import math

import cadquery as cq
from cadquery import Solid, Vector

HERE = os.path.dirname(os.path.abspath(__file__))
OUT = os.path.join(HERE, 'step', 'parts')
SRC = os.path.join(HERE, 'step', 'parts_pristine')

# Bu betigin UZERINE YAZDIGI Asama 1 govdeleri.
#
# NEDEN AYRI BIR DIZIN: cikti da OUT'a gittigi icin bu govdeler OUT'tan
# OKUNAMAZ -- ikinci kosuda betik kendi ciktisini girdi sanardi ve zaten
# burnu silindire trasanmis bir yuzeye yeniden burun ekleyip
# `Null TopoDS_Shape` ile coker (bkz. cad/MEKANIZMA_GUNLUGU.md). Girdi
# dokunulmamis haliyle SRC'de durur; oraya Asama 1 yazar. Boylece Asama 2
# istenildigi kadar tekrar kosulabilir ve `git checkout -- cad/step/` de
# artik tuzak degildir.
#
# Liste tek kaynaktir: Asama 1 de bunu buradan okur, kendi kopyasini tutmaz.
TURETILEN = frozenset({
    'wing', 'tailplane', 'vertical_stabiliser',   # mentese boslugu kesilir
    'elevon_left', 'elevon_right',                # burnu silindire trasanir
    'elevator_left', 'elevator_right', 'rudder',
    'pylon_left', 'pylon_right',                  # motor supurme boslugu kesilir
})
SDF_CANDIDATES = [
    os.environ.get('TILTROTOR_SDF', ''),
    os.path.join(os.path.dirname(HERE), 'tiltrotor_tailplane_model.sdf'),
    os.path.join(os.path.expanduser('~'), 'SOLOUAV', 'tiltrotor_tailplane_model.sdf'),
]

# --------------------------------------------------------------------------
# TASARIM SABİTLERİ — SDF'te karşılığı yok, mühendislik seçimi
# --------------------------------------------------------------------------
BRG_OD, BRG_ID, BRG_W = 10.0, 5.0, 4.0    # MR105ZZ
YOKE_ARM_T = 5.0                          # çatal kolu kalınlığı
YOKE_ARM_IN = 23.0                        # kol iç yüzünün eksenden y uzaklığı
YOKE_PLATE_T = 6.0
BOSS_R = 10.0                             # yatak bossu dış yarıçapı
MOTOR_R, MOTOR_H = 20.0, 35.0             # SDF motor silindiri (süpürme payı için)
CRADLE_IR, CRADLE_OR, CRADLE_H = 20.0, 23.0, 12.0
CRANK_R = 14.0
SERVO_L, SERVO_W, SERVO_H = 23.0, 12.0, 22.0
PUSHROD_R = 1.2
HINGE_PIN_R = 2.0
CLEAR = 1.0                               # genel kaçıklık payı

# Pylon/direk kutuları — build_tiltrotor_cad.py'deki BOXES ile aynı kaynak
# (oradan okunur; okunamazsa bu yedek kullanılır ve uyarı basılır).
PYLON_FALLBACK = {
    'pylon_right': ((217.5, -350.0, 40.0), (105.0, 30.0, 60.0)),
    'pylon_left':  ((217.5,  350.0, 40.0), (105.0, 30.0, 60.0)),
}
TAIL_POST_Z = (0.0, 30.0)                 # kuyruk direği: boom üstünden yoke altına

CHILD_PARENT = {          # kumanda yüzeyi -> bağlı olduğu ana gövde
    'elevon_left': 'wing', 'elevon_right': 'wing',
    'elevator_left': 'tailplane', 'elevator_right': 'tailplane',
    'rudder': 'vertical_stabiliser',
}
TILT_PARENT = {           # tilt grubu -> üzerine oturduğu gövde
    'motor_0_right': 'pylon_right', 'motor_1_left': 'pylon_left',
    'motor_2_tail': 'tail_pylon',
}


# --------------------------------------------------------------------------
def load_joints():
    """fusion_02_joints.py'nin ayrıştırıcısını ödünç al — ikinci bir kopya yazma."""
    sdf = next((p for p in SDF_CANDIDATES if p and os.path.isfile(p)), None)
    if sdf is None:
        raise SystemExit('model.sdf bulunamadi. TILTROTOR_SDF ile yol verin.\n  ' +
                         '\n  '.join(p for p in SDF_CANDIDATES if p))
    kod = open(os.path.join(HERE, 'fusion_02_joints.py'), encoding='utf-8').read()
    kod = re.sub(r'^import adsk\..*$', '', kod, flags=re.M)
    ns = {'__name__': 'fusion_02_joints_lib'}
    exec(compile(kod, 'fusion_02_joints.py', 'exec'), ns)
    return sdf, ns['parse_sdf_joints'](sdf)


def pylon_boxes():
    try:
        sys.path.insert(0, HERE)
        import build_tiltrotor_cad as b
        out = {}
        for name, c, s in b.BOXES:
            if name.startswith('pylon'):
                out[name] = (tuple(v * 1000.0 for v in c), tuple(v * 1000.0 for v in s))
        if out:
            return out
    except Exception as e:                                   # noqa: BLE001
        print('  uyari: build_tiltrotor_cad okunamadi ({}), yedek olculer'.format(e))
    return PYLON_FALLBACK


# --- geometri yardimcilari ------------------------------------------------
def bx(x0, x1, y0, y1, z0, z1):
    return Solid.makeBox(x1 - x0, y1 - y0, z1 - z0, Vector(x0, y0, z0))


def cy(p1, p2, r):
    d = Vector(*p2) - Vector(*p1)
    return Solid.makeCylinder(r, d.Length, Vector(*p1), d.normalized())


def uni(*shapes):
    out = shapes[0]
    for s in shapes[1:]:
        out = out.fuse(s)
    return out.clean()


def unit(v):
    n = math.sqrt(sum(c * c for c in v))
    return tuple(c / n for c in v)


def perp_frame(D, aft_hint=(-1.0, 0.0, 0.0)):
    """Eksene dik iki birim vektör: `aft` (gövde arkası) ve n = aft x D."""
    d = sum(aft_hint[i] * D[i] for i in range(3))
    aft = unit(tuple(aft_hint[i] - d * D[i] for i in range(3)))
    n = (aft[1] * D[2] - aft[2] * D[1],
         aft[2] * D[0] - aft[0] * D[2],
         aft[0] * D[1] - aft[1] * D[0])
    return aft, n


def along(A, D, t):
    return (A[0] + D[0] * t, A[1] + D[1] * t, A[2] + D[2] * t)


def offset(p, v, s):
    return (p[0] + v[0] * s, p[1] + v[1] * s, p[2] + v[2] * s)


def rot_about(shape, A, D, deg):
    return shape.rotate(Vector(*A), Vector(*along(A, D, 1.0)), deg)


def axis_radius(shape, A, D):
    """Gövdenin menteşe eksenine dik azami uzaklığı (köşelerden)."""
    rmax = 0.0
    for v in shape.Vertices():
        w = (v.X - A[0], v.Y - A[1], v.Z - A[2])
        t = sum(w[i] * D[i] for i in range(3))
        perp = tuple(w[i] - t * D[i] for i in range(3))
        rmax = max(rmax, math.sqrt(sum(c * c for c in perp)))
    return rmax


def axial_span(shape, A, D):
    ts = []
    for v in shape.Vertices():
        w = (v.X - A[0], v.Y - A[1], v.Z - A[2])
        ts.append(sum(w[i] * D[i] for i in range(3)))
    return min(ts), max(ts)


def lower_surface_z(shape, x, y, half=14.0):
    """Gövdenin (x,y) civarındaki en alt z'si — iniş takımı bağlantısı için."""
    bb = shape.BoundingBox()
    probe = bx(x - half, x + half, y - half, y + half, bb.zmin - 5, bb.zmax + 5)
    cut = shape.intersect(probe)
    return cut.BoundingBox().zmin


def load_part(name):
    """Asama 1 govdesini oku.

    Bu betigin DEGISTIRDIGI govdeler (`TURETILEN`) daima dokunulmamis
    kopyadan (`SRC`) okunur, `OUT`tan degil: `OUT` bu betigin kendi
    ciktisidir ve oradan okumak betigi ikinci kosuda kendi sonucunun
    uzerine surer. Degistirilmeyen govdeler `OUT`tan okunur.
    """
    if name in TURETILEN:
        p = os.path.join(SRC, name + '.step')
        if not os.path.isfile(p):
            raise SystemExit(
                'dokunulmamis kopya yok: {}\n'
                'Asama 2 bu govdeyi degistirdigi icin girdisini {}/ altindan\n'
                'okur, step/parts/ altindan degil. Once Asama 1 kosun\n'
                '(build_tiltrotor_cad.py) -- kopyalari o yazar.'.format(
                    p, os.path.basename(SRC)))
    else:
        p = os.path.join(OUT, name + '.step')
        if not os.path.isfile(p):
            raise SystemExit('parca yok: ' + p)
    return cq.importers.importStep(p).val()


# --------------------------------------------------------------------------
# 1) TILT GRUBU
# --------------------------------------------------------------------------
def build_tilt(tag, A, post_bot, post_top):
    """A = menteşe noktası (mm). Eksen y boyunca; direk `post_bot`..`post_top`."""
    XA, YC, ZA = A
    S = -1.0 if YC <= 0 else 1.0
    def Y(off):
        return YC + S * off
    parts = {}

    # motor pucunun eksen etrafında süpürdüğü yarıçap
    sweep_r = math.sqrt(MOTOR_R ** 2 + (MOTOR_H / 2.0) ** 2) + 1.4

    ai, ao = YOKE_ARM_IN, YOKE_ARM_IN + YOKE_ARM_T
    yoke = bx(XA - 38, XA, min(Y(-ao), Y(ao)), max(Y(-ao), Y(ao)),
              ZA - 15, ZA - 15 + YOKE_PLATE_T)
    for a, b in ((ai, ao), (-ao, -ai)):
        yoke = uni(yoke,
                   bx(XA - 18, XA, min(Y(a), Y(b)), max(Y(a), Y(b)), ZA - 9, ZA),
                   cy((XA, Y(a), ZA), (XA, Y(b), ZA), BOSS_R))
    yoke = yoke.cut(cy((XA, Y(-ai), ZA), (XA, Y(ai), ZA), sweep_r))       # puc boşluğu
    yoke = yoke.cut(cy((XA, Y(ai - 1), ZA), (XA, Y(ao + 1), ZA), BRG_OD / 2))
    yoke = yoke.cut(cy((XA, Y(-ao - 1), ZA), (XA, Y(-ai + 1), ZA), BRG_OD / 2))
    parts['tilt_yoke_' + tag] = yoke

    for lbl, (a, b) in (('out', (ai, ai + BRG_W)), ('in', (-ai - BRG_W, -ai))):
        brg = cy((XA, Y(a), ZA), (XA, Y(b), ZA), BRG_OD / 2)
        brg = brg.cut(cy((XA, Y(a - 1), ZA), (XA, Y(b + 1), ZA), BRG_ID / 2))
        parts['tilt_bearing_{}_{}'.format(tag, lbl)] = brg

    cradle = cy((XA, YC, ZA - CRADLE_H / 2), (XA, YC, ZA + CRADLE_H / 2), CRADLE_OR)
    cradle = cradle.cut(cy((XA, YC, ZA - CRADLE_H), (XA, YC, ZA + CRADLE_H), CRADLE_IR))
    for a, b in ((ai - 1, ao + 1), (-ao - 1, -ai + 1)):
        cradle = uni(cradle, cy((XA, Y(a), ZA), (XA, Y(b), ZA), BRG_ID / 2))
    parts['tilt_cradle_' + tag] = cradle

    ck = bx(XA - 3, XA + 3, min(Y(ao + 1), Y(ao + 5)), max(Y(ao + 1), Y(ao + 5)),
            ZA - CRANK_R, ZA)
    ck = uni(ck, cy((XA, Y(ao + 1), ZA), (XA, Y(ao + 5), ZA), BRG_OD / 2))
    parts['tilt_crank_' + tag] = ck

    # servo, direğin içinde dikeyde ortalanır (pylon 60 mm, kuyruk direği 30 mm)
    sz0 = post_bot + (post_top - post_bot - SERVO_H) / 2.0
    sz1 = sz0 + SERVO_H
    sv = bx(XA - 36, XA - 13, min(Y(3), Y(15)), max(Y(3), Y(15)), sz0, sz1)
    shx = XA - 24
    sv = uni(sv, cy((shx, Y(15), (sz0 + sz1) / 2), (shx, Y(19), (sz0 + sz1) / 2), 3.0))
    parts['tilt_servo_' + tag] = sv
    hz = (sz0 + sz1) / 2
    parts['tilt_horn_' + tag] = bx(shx - 2, shx + 2, min(Y(19), Y(23)), max(Y(19), Y(23)),
                                   hz, hz + CRANK_R)
    parts['tilt_pushrod_' + tag] = cy((shx, Y(21), hz + CRANK_R),
                                      (XA, Y(ao + 3), ZA - CRANK_R), PUSHROD_R)
    return parts


# --------------------------------------------------------------------------
# 2) İNİŞ TAKIMI BAĞLANTISI
# --------------------------------------------------------------------------
def build_gear(wing, boom):
    parts = {}
    for tag, YC in (('right', -250.0), ('left', 250.0)):
        leg = load_part('leg_front_' + tag)
        top = leg.BoundingBox().zmax
        zs = lower_surface_z(wing, 220.0, YC)      # kanadın o istasyondaki alt yüzeyi
        s = uni(bx(208, 232, YC - 7, YC + 7, top, zs + 5.0),
                bx(190, 250, YC - 20, YC + 20, zs - 6.0, zs))
        parts['leg_front_{}_strut'.format(tag)] = s

    leg = load_part('leg_tail')
    top = leg.BoundingBox().zmax
    bb = boom.BoundingBox()
    # Dikmenin TAMAMI tailplane hücum kenarının önünde kalmalı. İlk sürümde
    # x1 = tp_le + 5 idi ve dikme (x1-20 .. x1) geriye taşıp tailplane'i kesiyordu;
    # dikme boyu kadar pay bırakılıyor.
    tp_le = load_part('tailplane').BoundingBox().xmax
    x1 = tp_le + 25.0
    t = uni(bx(x1 - 20, x1, -10, 10, top, bb.zmin),
            bx(x1 - 5, x1 + 55, -25, 25, bb.zmin - 6, bb.zmin),
            bx(x1 - 5, x1 + 55, -25, -20, bb.zmin, bb.zmax),
            bx(x1 - 5, x1 + 55, 20, 25, bb.zmin, bb.zmax))
    parts['leg_tail_strut'] = t
    return parts


# --------------------------------------------------------------------------
# 3) KUMANDA YÜZEYİ: menteşe boşluğu + tahrik
# --------------------------------------------------------------------------
def shape_hinge_nose(surf, A, D):
    """Kumanda yüzeyinin BURNUNU menteşe eksenine göre silindir yap.

    NEDEN: yüzeyin burnu silindirik olmadığı sürece (ölçüm: elevon burnunda
    yarıçap 2-11,6 mm arasında geziyor) ±44,7°'de sıyırmaması ancak yarıçapı
    o azami değere kadar büyük bir cepse mümkün. O cep de kanatta kocaman
    bir oyuk bırakıyor ve kumanda yüzeyi kanattan kopuk görünüyor.

    Gerçek kumanda yüzeyleri gibi: burun eksene göre silindire tıraşlanır,
    arkası aynen kalır. Böylece kanattaki boşluk r_burun + pay kadar olur
    ve menteşe hattı ince, düzgün bir çizgi haline gelir.
    """
    aft, n = perp_frame(D)
    t0, t1 = axial_span(surf, A, D)
    # Yarıçap, burnun AZAMİ YARIÇAPINDAN alınamaz: o yarıçaplı silindirle
    # kesmek tanım gereği hiçbir şeyi kesmez (ilk sürümde tıraşlama sessizce
    # işlemsiz kaldı, hacimler değişmedi). Menteşe ekseni yüzeyin orta
    # kalınlığında olduğu için doğru yarıçap YARIM KALINLIKTIR; ondan taşan
    # sivri burun kısmı tıraşlanır ve geriye gerçek bir yarım silindir kalır.
    ust, alt = 0.0, 0.0
    for v in surf.Vertices():
        w = (v.X - A[0], v.Y - A[1], v.Z - A[2])
        t = sum(w[i] * D[i] for i in range(3))
        perp = tuple(w[i] - t * D[i] for i in range(3))
        if sum(perp[i] * aft[i] for i in range(3)) <= 0.0:      # yalnız burun tarafı
            h = sum(perp[i] * n[i] for i in range(3))
            ust = max(ust, h)
            alt = max(alt, -h)
    # Eksen tam orta kalınlıkta DEĞİL (elevon z -11,5..0, orta -5,75; eksen -5).
    # Yarıçapı büyük tarafa göre almak silindiri üst yüzeyden 1,5 mm dışarı
    # taşırıyordu; küçük taraf alınırsa burun profilin içinde kalır.
    r_burun = min(ust, alt)
    if r_burun <= 0.0:
        return surf, 0.0
    # Burun SİVRİ olduğu için yalnız kesmek yetmez: silindirin içinde kalır ve
    # kanattaki silindirik cebe karşı yer yer 6 mm'ye varan yarık bırakır.
    # Gerçek kumanda yüzeyinde burun DOLU yarım silindirdir; o hacim EKLENİR.
    on_kutu = yari_uzay(A, D, tuple(-c for c in aft), t0, t1)
    silindir = cy(along(A, D, t0), along(A, D, t1), r_burun)
    burun_katisi = silindir.intersect(on_kutu)
    out = surf.fuse(burun_katisi).clean()
    # sonra fazlalık tıraşlanır: burun tam olarak r_burun yarıçapında kalsın
    tut = cy(along(A, D, t0 - 20), along(A, D, t1 + 20), r_burun)
    tut = tut.fuse(yari_uzay(A, D, aft, t0 - 20, t1 + 20)).clean()
    return out.intersect(tut).clean(), r_burun


def yari_uzay(A, D, aft, t0, t1):
    """Menteşe düzleminin ARKASINDA kalan büyük kutu (aft yönü pozitif)."""
    L = 4000.0
    kutu = Solid.makeBox(L, L, L, Vector(0, 0, 0))
    # kutuyu, bir yüzü menteşe ekseninden geçecek ve +aft yönüne bakacak
    # şekilde yerleştir
    hd = (aft[1] * D[2] - aft[2] * D[1],
          aft[2] * D[0] - aft[0] * D[2],
          aft[0] * D[1] - aft[1] * D[0])
    pl = cq.Plane(origin=Vector(*offset(along(A, D, (t0 + t1) / 2.0), aft, L / 2.0)),
                  xDir=Vector(*aft), normal=Vector(*hd))
    return cq.Workplane(pl).box(L, L, L).val()


def hinge_relief(surf, parent, A, D, lim_deg, r_burun=0.0):
    """Menteşe boşluğu: yüzeyin SAPMA ARALIĞI boyunca gövdeye giren
    malzemesinin azami yarıçapı + pay.

    ⛔ CEBİ YALNIZ BURUN YARIÇAPINA GÖRE AÇMA — DENENDİ VE ELENDİ.
    Burun `shape_hinge_nose` ile silindire tıraşlansa bile cep `r_burun +
    CLEAR` olamaz: kopmayı çözer ama sapma boyunca çakışma bırakır. Ölçüm
    (temiz tek geçiş, 3 Eylül 2026): elevatör∩tailplane 2,59 cm³,
    rudder∩fin 2,79 cm³ ve rudder daha **0°'de** gövdeye giriyor; kapı
    57 geçti / 6 uyarı veriyor. Süpürme yarıçapıyla 61 geçti / 2 uyarı.
    Bu yol günlükte zaten elenmişti (bkz. cad/MEKANIZMA_GUNLUGU.md) ama
    kodda canlı dal olarak kalmıştı — Aşama 2 ikinci kez koşulamadığı için
    ürettiği geometri kimsenin gözüne girmiyordu.

    Burun yarıçapı yalnızca ALT SINIR olarak kullanılır: tıraşlanmış burun
    cebe sığmalı, ama cebi süpürme belirler.
    """
    rmax = 0.0
    for deg in (-lim_deg, -lim_deg / 2, 0.0, lim_deg / 2, lim_deg):
        try:
            hit = parent.intersect(rot_about(surf, A, D, deg))
        except Exception:                                      # noqa: BLE001
            continue
        if hit.Volume() > 1e-3:
            rmax = max(rmax, axis_radius(hit, A, D))
    R = max(rmax, r_burun)
    if R <= 0.0:
        return None, 0.0
    R += CLEAR
    t0, t1 = axial_span(surf, A, D)
    return cy(along(A, D, t0 - 10), along(A, D, t1 + 10), R), R


def build_actuation(tag, A, D, s25, s50, s75):
    """Menteşe pimleri + korna. Servo yerleşimi yüzeye göre değişir:
    elevon kanadın içine sığar, elevatör/rudder sığmaz (tailplane 9,9 mm,
    fin 16,5 mm; 22 mm'lik servo girmez) — onlar boom'a gömülür."""
    aft, n = perp_frame(D)
    parts = {}
    pins = None
    for s in (s25, s75):
        c = along(A, D, s)
        p = cy(along(c, D, -12), along(c, D, 12), HINGE_PIN_R)
        pins = p if pins is None else uni(pins, p)
    parts['hinge_pins_' + tag] = pins

    if tag.startswith('elevon'):
        # korna yüzeyin ortasında, servo kanadın içinde menteşenin önünde
        hc = offset(along(A, D, s50), aft, 6.0)
        parts['horn_' + tag] = bx_oriented(offset(hc, n, 9.0), aft, D, 8.0, 3.0, 18.0)
        sc = offset(along(A, D, s50), aft, -45.0)
        sv = bx_oriented(sc, aft, D, SERVO_L, SERVO_W, SERVO_H)
        sv = uni(sv, cy(offset(sc, D, 6), offset(sc, D, 10), 3.0),
                 bx_oriented(offset(offset(sc, D, 8.0), n, 7.0), aft, D, 4.0, 3.0, CRANK_R))
        parts['servo_' + tag] = sv
        parts['pushrod_' + tag] = cy(offset(offset(sc, D, 8.0), n, CRANK_R),
                                     offset(hc, n, 18.0), PUSHROD_R)
    return parts, aft, n


def bx_oriented(c, ld, wd, L, W, H):
    """Merkezi c olan, ld/wd eksenlerine oturmuş kutu (H = ld x wd yönünde).

    cq.Plane kullanılıyor: normal=hd, xDir=ld verildiğinde yDir = hd x ld = wd
    olur (ld ile wd birim ve dik olduğu sürece), yani kutunun L/W/H kenarları
    tam olarak ld/wd/hd yönlerine oturur.
    """
    hd = (ld[1] * wd[2] - ld[2] * wd[1],
          ld[2] * wd[0] - ld[0] * wd[2],
          ld[0] * wd[1] - ld[1] * wd[0])
    pl = cq.Plane(origin=Vector(*c), xDir=Vector(*ld), normal=Vector(*hd))
    return cq.Workplane(pl).box(L, W, H).val()


def build_tail_actuation(boom, J):
    """Elevatör ve rudder servoları kuyruk çubuğuna gömülür; rudder'ın mil
    ekseni z olduğu için 22 mm servo 20 mm boom'a sığmaz, altına karina eklenir."""
    bb = boom.BoundingBox()
    hw = bb.ymax                       # boom yarı genişliği
    parts = {}
    # Servolar tailplane_strut'ın (x -725..-675) ARKASINDA kalmalı; ilk sürüm
    # dx=+20/+50 ile strut'a giriyordu (dogrula_mekanizma [5] yakaladı).
    for tag, S, dx in (('right', -1.0, -35.0), ('left', 1.0, -7.0)):
        A = J['elevator_' + tag]['point']
        XS = A[0] + dx
        ys0, ys1 = (-18.0, 4.0) if S < 0 else (-4.0, 18.0)
        sv = uni(bx(XS, XS + SERVO_L, ys0, ys1, A[2] + 23, A[2] + 35),
                 cy((XS + 11.5, ys0 if S < 0 else ys1, A[2] + 29),
                    (XS + 11.5, S * (hw + 10), A[2] + 29), 3.0),
                 bx(XS + 8, XS + 15, min(S * (hw + 13), S * (hw + 9)),
                    max(S * (hw + 13), S * (hw + 9)), A[2] + 29, A[2] + 43))
        parts['servo_elevator_' + tag] = sv
        parts['horn_elevator_' + tag] = uni(
            bx(A[0] - 4, A[0] + 4, min(S * (hw + 17), S * (hw + 13)),
               max(S * (hw + 17), S * (hw + 13)), A[2] - 18, A[2]),
            cy((A[0], S * (hw + 17), A[2]), (A[0], S * (hw + 13), A[2]), 3.0))
        parts['pushrod_elevator_' + tag] = cy(
            (XS + 11.5, S * (hw + 11), A[2] + 43), (A[0], S * (hw + 15), A[2] - 16), PUSHROD_R)

    A = J['rudder']['point']
    parts['servo_fairing_rudder'] = bx(A[0] - 17, A[0] + 14, -14, 14, bb.zmin - 6, bb.zmin + 2)
    rs = uni(bx(A[0] - 13, A[0] + 10, -11, 11, bb.zmin - 4, bb.zmin + 18),
             cy((A[0] - 1.5, 0, bb.zmin + 18), (A[0] - 1.5, 0, bb.zmin + 34), 3.0),
             bx(A[0] - 5, A[0] + 2, 3, 17, bb.zmin + 30, bb.zmin + 37))
    parts['servo_rudder'] = rs
    parts['horn_rudder'] = uni(bx(A[0] - 4, A[0] + 4, 3, 21, A[2] - 84, A[2] - 76),
                               cy((A[0], 0, A[2] - 80), (A[0], 6, A[2] - 80), 3.0))
    parts['pushrod_rudder'] = cy((A[0] - 1.5, 15, bb.zmin + 33.5),
                                 (A[0], 19, A[2] - 80), PUSHROD_R)
    return parts
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

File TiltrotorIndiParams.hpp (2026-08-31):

/****************************************************************************
 *
 *   Copyright (c) 2026 PX4 Development Team. All rights reserved.
 *
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
 * 1. Redistributions of source code must retain the above copyright
 *    notice, this list of conditions and the following disclaimer.
 * 2. Redistributions in binary form must reproduce the above copyright
 *    notice, this list of conditions and the following disclaimer in
 *    the documentation and/or other materials provided with the
 *    distribution.
 * 3. Neither the name PX4 nor the names of its contributors may be
 *    used to endorse or promote products derived from this software
 *    without specific prior written permission.
 *
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
 ****************************************************************************/

#pragma once

// 1:1 constants from tiltrotor_Matlab files/tiltrotor_params.m and
// gain_schedule.m. These describe the fixed physical geometry of the
// gz_tiltrotor_tailplane airframe (CA_ROTOR*_P{X,Y,Z}/KM in
// 4022_gz_tiltrotor_tailplane) and are not meant to be runtime-tuned the
// way rate/attitude gains normally are in PX4 -- the MATLAB reference
// itself hardcodes them as literals (not as tunable "params"), so this
// mirrors that design rather than inventing a new INDI_* param group.

namespace tiltrotor_indi
{

// --- allocator width (step 45, 2026-08-03, item (V)) ---
// 6 rotor channels [T0 T1 T2 d0 d1 d2] + 5 aerodynamic control surfaces.
// The surfaces used to be held at zero ("out of scope for the ported
// controller"), and step 43 measured what that cost: with no aerodynamic
// attitude authority, ALL of it has to come from the rotors, so the rotors can
// never be shut down and the vehicle cannot become fully wing-borne -- at
// 20.6 m/s both WING rotors were already at 0.0 N while the TAIL rotor still
// carried 21.8 N purely to hold pitch, with the allocator 20% saturated.
static constexpr int N_ACT = 11;

// --- aerodynamic control surfaces (surface index 0..4 -> u index 6..10) ---
// Transcribed 1:1 from Tools/simulation/gz/models/tiltrotor_tailplane/model.sdf
// LiftDrag plugins, WITH the FLU->FRD conversion (x, -y, -z) applied -- skipping
// that same conversion is what made blocker B4 look like a sign contradiction
// for months (step 34).
//   servo_0/1  left/right ELEVON    cp FLU (-0.05, +-0.30, 0.05)  area 0.5    rad_to_cl -4.0
//   servo_2/3  left/right ELEVATOR  cp FLU (-0.70, +-0.15, -0.04) area 0.048  rad_to_cl -12.0
//   servo_4    RUDDER               cp FLU (-0.74, 0, 0.12)       area 0.032  rad_to_cl -6.0
// Force model: F = qbar * k * delta * e_up applied at cp, LINEAR in delta, so
// the Jacobian is delta-independent and scales only with qbar = 0.5*rho*V^2.
// e_up: servos 0-3 FLU (0,0,1) -> FRD (0,0,-1); rudder FLU (0,1,0) -> FRD (0,-1,0).
static constexpr int N_SURF = 5;
// RUDDER -0.74 -> -0.86 (step 132): the fin moved aft because the tail rotor
// disc passed through it at tilt = 0, i.e. for the whole hover phase.
static constexpr float SURF_CPX[N_SURF] = { -0.05f, -0.05f, -0.70f, -0.70f, -0.78f };
static constexpr float SURF_CPY[N_SURF] = { -0.30f, +0.30f, -0.15f, +0.15f,  0.00f };
static constexpr float SURF_CPZ[N_SURF] = { -0.05f, -0.05f, +0.04f, +0.04f, -0.10f };
static constexpr float SURF_EX[N_SURF]  = {  0.0f,   0.0f,   0.0f,   0.0f,   0.0f };
static constexpr float SURF_EY[N_SURF]  = {  0.0f,   0.0f,   0.0f,   0.0f,  -1.0f };
static constexpr float SURF_EZ[N_SURF]  = { -1.0f,  -1.0f,  -1.0f,  -1.0f,   0.0f };
// k = area * rad_to_cl (N per Pa per rad), sign included.
static constexpr float SURF_K[N_SURF] = { -2.0f, -2.0f, -0.576f, -0.576f, -0.192f };
// Deflection limits are the model.sdf JOINT limits, not a software choice.
static constexpr float SURF_MAX[N_SURF] = { 0.78f, 0.78f, 0.52f, 0.52f, 0.52f };
static constexpr float SURF_RATE_MAX = 4.0f;   // rad/s (servo slew, sets the box)
static constexpr float RHO_AIR = 1.225f;       // kg/m^3
// WU_SURF -- the surfaces' WLS penalty, and it is a DERIVATION, not a taste.
// gain_schedule.m's documented rule: the WLS prefers actuator i over j when
// Wu_i/|G_i| < Wu_j/|G_j| (penalty per unit torque). Because the surfaces' |G|
// grows with qbar, a CONSTANT WU_SURF automatically yields "expensive in hover,
// cheap in cruise" -- the handover point is the crossing of a RATIO, not a mode
// switch, which is why no state machine is needed.
// Placed at FT_CRUISE_V = 8 m/s:
//   qbar(8) = 39.2 Pa; elevon roll effectiveness 0.6*qbar = 23.5 N*m/rad
//   rotor tilt roll effectiveness ~ T*0.05 ~ 0.45 at cruise thrust (~9 N)
//   WU_TILT_CRUISE = 1.5 -> tilt penalty per unit torque = 1.5/0.45 = 3.33
//   equate: WU_SURF/23.5 = 3.33 -> 78.3 -> 80
// The per-axis crossovers that follow are PHYSICALLY right (a smaller surface
// takes over later): roll ~8 m/s, pitch (elevator) ~10 m/s, yaw (rudder, |G| 4x
// smaller) ~16 m/s.
// !! NOT to be treated as correct until measured in SITL: step 7 changed a
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

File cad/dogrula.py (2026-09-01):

#!/usr/bin/env python3
"""cad/step çıktısını kaynak SDF'e karşı bağımsız olarak doğrular.

Üretici betiğin tablolarını KULLANMAZ; SDF'i baştan ayrıştırır, böylece
elle aktarma hataları da yakalanır.

Kontroller:
  1. Kapsam      — SDF'teki her görünür parçanın CAD karşılığı var mı
  2. Ölçü        — kutu/silindir parçaların bbox'ı SDF ile birebir mi
  3. Mesh zarfı  — loft edilen parçalar mesh sınırları içinde mi
  4. Katı sağlığı— her STEP tek, kapalı, geçerli katı mı
  5. Menteşe     — her eklem noktası ilgili katının içinde mi
  6. Girişim     — duruşta parçalar birbirine giriyor mu
  7. Tilt süpürme— pervane diski 0…90° arasında neye çarpıyor
                   (eklem <upper> tavanının ötesi 'limit dışı' işaretlenir)
  8. Yüzey sapma — elevon/elevatör/rudder tam açıda neye çarpıyor
                   (ortalama film kalınlığıyla yargılanır, hacimle değil)
"""
import os
import re
import math
import glob
import numpy as np
import cadquery as cq
from cadquery import Vector

HERE = os.path.dirname(os.path.abspath(__file__))
SDF = os.path.join(os.path.dirname(HERE), 'tiltrotor_tailplane_model.sdf')
PARTS = os.path.join(HERE, 'step', 'parts')
MM = 1000.0
TOL = 0.5          # mm — kabul edilen ölçü sapması

_ok, _warn, _err = [], [], []


def ok(m):
    _ok.append(m)
    print('  ok     ' + m)


def warn(m):
    _warn.append(m)
    print('  UYARI  ' + m)


def err(m):
    _err.append(m)
    print('  HATA   ' + m)


_model = []


def model(m):
    """CAD doğru ama kaynak SDF'in kendi geometrisi çakışıyor."""
    _model.append(m)
    print('  MODEL  ' + m)


_info = []


def info(m):
    """Eklem limitinin dışındaki açı: araç oraya gidemez, bulgu sayılmaz.

    Yine de yazdırılır — limit ileride gevşetilirse bedelinin ne olacağı
    kayıtlı kalsın diye (bkz. model.sdf motor_2_joint <upper> notu).
    """
    _info.append(m)
    print('  limit dışı  ' + m)


# --------------------------------------------------------------- SDF ayrıştırma
def parse_sdf(path):
    s = open(path).read()
    links = {}
    for lm in re.finditer(r"<link name=['\"]([^'\"]+)['\"]>(.*?)</link>", s, re.S):
        name, body = lm.group(1), lm.group(2)
        # <inertial> içindeki pose kütle merkezidir, linkin yerleşimi değil;
        # ayıklanmazsa elevon menteşesi 300 mm kayıyor.
        head = re.sub(r'<inertial>.*?</inertial>', '', body, flags=re.S)
        head = head[:head.find('<visual')] if '<visual' in head else head
        lp = re.search(r'<pose>([^<]+)</pose>', head)
        link_pose = [float(v) for v in lp.group(1).split()] if lp else [0.] * 6
        vis = []
        for vm in re.finditer(r"<visual name=['\"]([^'\"]+)['\"]>(.*?)</visual>", body, re.S):
            vn, vb = vm.group(1), vm.group(2)
            pm = re.search(r'<pose>([^<]+)</pose>', vb)
            pose = [float(v) for v in pm.group(1).split()] if pm else [0.] * 6
            box = re.search(r'<box>\s*<size>([^<]+)</size>', vb)
            cyl = re.search(r'<cylinder>\s*<length>([^<]+)</length>\s*<radius>([^<]+)</radius>', vb, re.S)
            mesh = re.search(r'<uri>([^<]+)</uri>', vb)
            g = None
            if box:
                g = ('box', [float(v) for v in box.group(1).split()])
            elif cyl:
                g = ('cylinder', [float(cyl.group(1)), float(cyl.group(2))])
            elif mesh:
                g = ('mesh', mesh.group(1).rsplit('/', 1)[-1])
            vis.append((vn, pose, g))
        links[name] = dict(pose=link_pose, visuals=vis)
    joints = {}
    for jm in re.finditer(r"<joint name=['\"]([^'\"]+)['\"] type=['\"]revolute['\"]>(.*?)</joint>", s, re.S):
        n, b = jm.group(1), jm.group(2)
        pm = re.search(r'<pose>([^<]+)</pose>', b)
        joints[n] = dict(
            child=re.search(r'<child>([^<]+)</child>', b).group(1),
            parent=re.search(r'<parent>([^<]+)</parent>', b).group(1),
            pose=[float(v) for v in pm.group(1).split()] if pm else [0.] * 6,
            axis=[float(v) for v in re.search(r'<xyz>([^<]+)</xyz>', b).group(1).split()],
            lower=float(re.search(r'<lower>([^<]+)</lower>', b).group(1)),
            upper=float(re.search(r'<upper>([^<]+)</upper>', b).group(1)),
            upmf='<use_parent_model_frame>1' in b)
    return links, joints


# --------------------------------------------------------------- yardımcılar
def load(name):
    return cq.importers.importStep(os.path.join(PARTS, name + '.step')).val()


def bb(shape):
    b = shape.BoundingBox()
    return np.array([b.xmin, b.ymin, b.zmin]), np.array([b.xmax, b.ymax, b.zmax])


def box_bbox(center, size):
    c, s = np.array(center) * MM, np.array(size) * MM
    return c - s / 2, c + s / 2


def common_volume(a, b):
    """İki katının ortak hacmi [mm^3]; kesişmiyorsa 0."""
    from OCP.BRepAlgoAPI import BRepAlgoAPI_Common
    lo_a, hi_a = bb(a)
    lo_b, hi_b = bb(b)
    if (hi_a < lo_b - 1e-6).any() or (hi_b < lo_a - 1e-6).any():
        return 0.0
    alg = BRepAlgoAPI_Common(a.wrapped, b.wrapped)
    if not alg.IsDone():
        return float('nan')
    r = cq.Shape.cast(alg.Shape())
    if not r.Solids():
        return 0.0
    return sum(s.Volume() for s in r.Solids())


def rot_y(shape, pivot, deg):
    return shape.rotate(Vector(pivot[0], pivot[1] - 1, pivot[2]),
                        Vector(pivot[0], pivot[1] + 1, pivot[2]), deg)


def rot_about(shape, pivot, axis, deg):
    a = np.array(axis, float)
    a = a / np.linalg.norm(a)
    p0 = Vector(*(np.array(pivot) - a))
    p1 = Vector(*(np.array(pivot) + a))
    return shape.rotate(p0, p1, deg)
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

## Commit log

2026-08-31 Tilt-rotor INDI ucus kontrolu
    [elevator_left.step, elevator_right.step, elevon_left.step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]
2026-08-31 Inis komutunu z0 datumuna bagla (Adim 148)
    run_mission_test.py iki yerde EKF yerel orijininin zeminde oldugunu
    varsayiyordu: flare hedefi (0.0 + TOUCH_Z) ve cikis kapisi (-0.25).
    OLCULDU (6 kosum, tam ayrisma): arm anindaki z kosumdan kosuma
    -1.013 .. +0.903 m arasinda degisiyor.
    z(arm) +0.903, +0.506 -> arac 0.75-0.87 m'de HAVADA ASILI kaldi
    z(arm) -1.013 .. +0.023 -> temiz indi
    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
2026-08-31 H6: HITL airframe 14003 + kopru kanal eslemesi (Adim 149)
    14003_tiltrotor_indi_hitl eklendi. 14002'yi KOPYALAMAZ, kaynak gosterir
    (. ${R}etc/init.d/airframes/14002_tiltrotor_indi): airframe betikleri
    rc.autostart tarafindan '.' ile source ediliyor, yani zincir calisiyor.
    Boylece cikis fonksiyonlari, tilt servo olcekleri ve .post durdurma
    listesi tek yerde kalir; iki dosyanin ayrismasi imkansiz.
    Uzerine yalnizca HITL farklari: SYS_HITL 1, HIL_ACT_FUNC1..11 (14002'nin
    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
2026-08-31 Fizik tabanli temas olcutu (Adim 150)
    Temas dogrulamasinin butun yollari IRTIFA sinyaline dayaniyordu ve
    yanilan sinyal tam olarak oydu. Olculdu (6 kosum): arac yerde otururken
    datum tabanli agl 0.64-1.15 m gosterdi, betik 'temas dogrulanamadi'
    deyip motorlari kesti. Iki kosumda arac gercekten 0.8 m'de asili kaldi
    ve kesme sonrasi DUSTU -- olculen carpma 3.0 ve 5.8 m/s.
    EKLENEN, irtifadan TAMAMEN bagimsiz: dikey itki agirligin yarisinin
    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
2026-08-31 Yer etkisi duzeltmesi + irtifa cetveli + B0 kaydi (Adim 151-152)
    YER ETKISI (Adim 152): arac son 1-2 metreyi inemiyordu, yer etkisinde
    asili kaliyordu. Tahsisat suclu DEGIL -- komut edilen ve gerceklesen itki
    birebir ayni (0.1 N). Suclu, irtifa dongusune giren HIZ.
    OLCULDU (ULog 15_22_05, lpos.vz eksi EKF'in konum turevi z_deriv):
    20-45 m: -0.12 | 10-20 m: -0.02 | 5-10 m: +0.15
    2-5 m : +0.32 | 1-2 m : +0.40 | 0-1 m: +0.38
    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
    [windy_tiltrotor.sdf]
2026-08-31 Inis dizisi MODULE tasindi (Adim 153 -- madde B0)
    SORUN: inis profili (kademeli alcalma, flare, temas) PC tarafindaki
    run_mission_test.py icindeydi ve o betik hedefi
    'px4-mc_indi_tiltrotor test_sp' POSIX KABUK ISTEMCISIYLE gonderiyordu.
    O yol yalnizca SITL'de var (indi_sitl_common.py basligi: 'external
    MAVLink clients cannot publish arbitrary uORB topics'). Kartta karsiligi
    yok ve flight_mode_manager/mc_pos_control bu airframe'de bilerek
    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
2026-08-31 TAM GOREV modulde: missionSequencer (Adim 154 -- B0 KAPANDI)
    Adim 153 inis PROFILINI tasimisti; bu, BAYRAKLARI da tasir. Tek
    mission_enable ile butun gorev modulden yurur:
    CLIMB -> HOVER -> FWD -> CRUISE -> FW -> FW_CRUISE -> BACK -> SETTLE
    -> LAND -> DONE.
    Dizici mevcut durum makinelerinin USTUNDE durur; gecisleri yine
    forwardTransition/backTransition/fixedWing*/landingSequence yurutur.
    Gecis kosullari OLAY tabanli (ft_state==CRUISE, fw_state==ACTIVE,
    bt_state==HANDOFF, land_state==TOUCHDOWN); yalnizca seyir sureleri
    zamanli. Zaman asiminda GERI GECISE duser -- her arizada arac hover'a
    donup iner.
    IKI HATA YAPILDI VE OLCULEREK BULUNDU:
    1. pos_hold her evrede aciktı. Pozisyon dongusu iler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
    [MulticopterIndiTiltrotor.cpp, TiltrotorIndiControl.hpp, TiltrotorIndiParams.hpp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]
2026-08-31 CAD ve kuyruk geometrisi esitlendi; strut girisimi duzeltildi (Adim 154)
    CAD, SDF'in guncel haline esitlendi: kuyruk motoru x=-550, fin x=-780
    z=100, rudder x=-870 z=100, cubuk 710 mm. CAD bunlarin hicbirini
    bilmiyordu (hala -650/-900/-990/800 tasiyordu).
    DOGRULAMA GERCEK BIR HATA YAKALADI: fini one+asagi alinca tailplane_strut
    fine 4.9 cm^3 GIRIYOR. Strut'un ust yuzu cubugun 15 mm USTUNE tasiyordu;
    fin -0.90/z0.12'deyken zararsizdi (5 mm bosluk), simdi degil. Strut'un tek
    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
    [elevator_left.step, elevator_right.step, elevon_left.step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]
2026-08-31 Eve donus + burnu eve cevir (Adim 155)
    Gorev 683 m uzaga gidip ORAYA iniyordu (kullanici: 'ucak alandan cikiyor',
    'inisi goremedim bile'). Eski test betiginde de donus yoktu.
    EKLENEN: MissionState::RETURN (BACK ile SETTLE arasinda). Ev gorev basinda
    yakalanir; donus multikopter modunda, pozisyon dongusu <=3 m/s'de
    dogrulanmis oldugu icin. Ayri zaman siniri 400 s.
    IKINCI SORUN: arac 683 m'yi GERI GERI geldi (ileri hiz -2.93 m/s, burun
    evden 163 derece sapik). Pozisyon dongusu hedefe goturur ama burnu
    cevirmez. RETURN'de yaw_sp = eve kerteriz; yakinda kerteriz gurultulendigi
    icin donduruldu.
    OLCULDU: ileri hiz -2.93 -> +2.96 m/s, aci -163.2 -> +2.9 derece,
    inis 683 m uzak -> eve 0.44 m. 11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
    [MulticopterIndiTiltrotor.cpp, TiltrotorIndiControl.hpp, TiltrotorIndiParams.hpp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]
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2026-08-31 B1 failsafe: SITL tarafi kapandi (Adim 161)
    Kontrol listesi B1'i '100+ m suruklenme' ile acik gosteriyordu, ama bu
    SITL'de OLCULEBILIR ve run_failsafe_test.py zaten var. Uc seviye kosuldu,
    HEPSI GECTI:
    seviye 1 (bozulma) 9/9 -- arac dusmuyor (-0.03 m/s), motor
    kesilmiyor, BIG_M 0, |w|max 0.155
    seviye 2 (NO_ALT) 3/3
    seviye 3 (durus kaybi) 7/7 -- kesme 0.036 s'de, commander lockdown'ini
    BEKLEMIYOR (49.06 vs 49.08 s)
    KAYITLI YAPISAL TAVAN: seviye 2/3'e SITL'de yalnizca TUM yardimi keserek
    varilabiliyor, commander +0.02 s icinde TERMINATION'a giriyor. O dal
    govdeleri anlamli sure calistirilamiyor (Adim 34/35 tavani).
    ACIK KALAN y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
2026-09-01 CAD mekanizma asamasi: tilt grubu, inis takimi baglantisi, mentese/tahrik donanimi + bagimsiz kapi
    Model imalat acisindan eksikti: tilt ekseni dolu bir blogun ortasindan gecen matematiksel bir cizgiydi (yatak/mil/servo yok), inis takimlari govdeye 133 mm uzakta bosluktaydi, kuyruk motoru hicbir seye degmiyordu, kumanda yuzeylerinin burnu silindirik olmadigi icin sapinca ana govdeye siniyordu.
    Yeni: cad/build_mechanism.py -- mesh GEREKTIRMEZ, eksenleri model.sdf'ten alir (ayristiriciyi fusion_02_joints.py'den odunc alir, ucuncu kopya yazmaz), mentese bosluklarini mevcut STEP govdelerinden keser. Uretilen: 3 nacelle tilt grubu (catal + MR105ZZ yatak + kizak + krank + servo + itki cubugu), kuy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
    [boom_brace_left.step, boom_brace_right.step, elevator_left.step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]
2026-09-01 Pervane ucu duzeltildi: dis pala kesitleri yeniden insa ediliyor
    Sikayet: "pervanenin ucu dalgali, tam bir ovallik yok". Iki ayri kusur cikti.
    Dalgalanma: 61 mesh kesiti loft'un tam icinden gectigi icin istasyon-istasyon gurultu dogrudan yuzeye yansiyordu. smooth_stations aciklik boyunca yumusatiyor -- veter dizisindeki yon degisimi 15/59 -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
    Uc ovalligi: iris_prop_cw.dae bir GORSEL mesh; dis palada kabuk 0,2 mm'ye, en ucta 0,01 mm'ye iniyor ve o kadar inceyi dilimleyince kontur kendi ustune katlaniyor. Uc yuzeyinin alani kendi sinirlayic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
    rebuild_thin_sections olculen VETER, BURULMA ve KESIT MERKEZINI korur (bunlar istasyondan istasyona duzgun deg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
    [boom_brace_left.step, boom_brace_right.step, elevator_left.step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]
2026-09-01 Pervane: yeniden kurulan kesitler yay uzunluguna gore ornekleniyor
    Onceki commit kesitleri duzeltmisti ama gorsel bozukluk devam ediyordu. Sebep parametrelendirme uyusmazligiydi: olculen kesitler resample() ile YAY UZUNLUGUNA gore ornekleniyor, benim urettigim elips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
    Duzeltme: elips once yogun (400 nokta) uretilip resample(n=40, start_by='maxx') ile indiriliyor, yani olculen kesitlerle birebir ayni konvansiyon.
    Katinin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
    [boom_brace_left.step, boom_brace_right.step, elevator_left.step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]
2026-09-01 Pala ucu yuvarlatildi, winglet loft tasmasi giderildi, kenar tirtiklanmasi azaltildi
    Uc gorsel kusur, uc ayri kok neden.
    1) Pala ucu kut: loft son istasyonda bitince OCC ucu DUZ yuzle kapatiyordu (uctan 0,3 mm'de kesit alani zaten 10,1 mm2). round_blade_tips ceyrek elips kapak koyuyor. Kapak DISARI eklenmez, mevcut ucun icine oturtulur -- yoksa pervane capi 256,7 -> 264,2 mm buyur. Kapak boyu uc veterinden turetilmez (uctan 4,4 mm ama 18 mm iceride 20 mm); 4/8/12 mm denendi, alani sicratti. PROP_TIP_CAP=18 mm ile alan 0,9 3,9 6,7 9,1 11,3 diye kademeli aciliyor.
    2) Winglet ucundaki siyah artik: kesitler saglamdi (dolgu 0,67-0,77); veter son 7 mm'de 111 -> 68 -> 20 mm'ye cokuyor ve makeLoft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
    [boom_brace_left.step, boom_brace_right.step, elevator_left.step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]
2026-09-01 Pervane gecis kirigi: kalinlik ALAN surekliliginden turetiliyor
    "Sag kisminda kirik gibi" sikayetinin kaynagi, yeniden kurulan elips ile olculen kamburlu profil arasindaki gecisteki alan centigiydi. Olcum (x=290..340 mm kesit alani):
    kalinlik egiliminden : 38,1 29,9 24,7 30,5 30,6 31,3 <- V centigi (inip cikiyor)
    alan surekliliginden : 38,0 30,1 23,5 24,9 25,5 26,0 <- tek yonlu
    Elips ile kamburlu profilin dolgu oranlari farkli oldugu icin kalinligi komsulardan tasimak alani bozuyordu. Gorunen buyukluk alan oldugundan hedef alan komsulardan tasinip elipsin kalinligi ondan cozuluyor: A = pi/4 * veter * t.
    Ayrica GECIS HARMANI denendi ve GERI ALINDI: sinira yakin saglam istasyonlari d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
    [boom_brace_left.step, boom_brace_right.step, elevator_left.step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]
2026-09-01 Mentese hatti: kumanda yuzeyinin burnu silindire trasaniyor, kanattaki bosluk yariya iniyor
    Sikayet: "kanatciklarin kanatla birlesme yeri cok ayrik". Dogru, ve sebebi benim actigim boslugun buyuklugu: yuzeyin burnu silindirik olmadigi icin (olcum: elevon burnunda yaricap 2-11,6 mm arasinda geziyor) +-44,7 derecede siyirmamasi ancak yaricapi o azami degere kadar buyuk bir cep ile mumkundu. O cep kanatta kocaman bir oyuk birakiyor, ince elevon onu doldurmuyordu.
    Gercek kumanda yuzeyleri gibi yapildi: shape_hinge_nose burnu mentese eksenine gore silindire trasliyor (arkasi aynen kaliyor), sonra kanat yalnizca r_burun + 1 mm kadar bosaltiliyor.
    Bosluk yaricapi:
    elevon_left 20,09 -> 8,96 mm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
    [boom_brace_left.step, boom_brace_right.step, elevator_left.step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]
2026-09-01 Mentese burnu dolu yarim silindire tamamlaniyor: elevon-kanat boslugu 11 mm -> 0,2 mm
    Sikayet: "keskin bir bosluk var, yapboz gibi oturmuyor". Iki ayri hata vardi.
    1) Ilk trasama sessizce ISLEMSIZDI: yaricapi "burnun azami yaricapi" olarak hesaplayip o yaricapli silindirle kesince tanim geregi hicbir sey kesilmiyor (hacimler hic degismemisti). Dogrusu yaricapi KALINLIKTAN almak.
    2) Burun SIVRI oldugu icin kesmek yetmiyor: silindirin icinde kalir ve silindirik cebe karsi yer yer 6 mm yarik birakir. Gercek kumanda yuzeyinde burun DOLU yarim silindirdir; o hacim EKLENIYOR (elevon 125,19 -> 127,65 / 133,00 cm3).
    Yaricap iki taraftan KUCUGUNE gore aliniyor: mentese ekseni tam orta kalinlikta d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
    [boom_brace_left.step, boom_brace_right.step, elevator_left.step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]
2026-09-02 MONTAJ.md: +26 derece elevator durdurucusu olcumle duzeltildi; Asama 2'nin idempotent olmadigi kayda gecti
    +26 derece iyimsermis: kati govde uzerinde 1 derece adimlarla olculdugunde elevator kuyruk cubuguna +24'te degmeye basliyor (+22 son tam temiz aci); +26'da girisim 0,020 cm3, +29,8'de 0,098 cm3. Temiz sinir ~+23 derece. Olcum dogrula_mekanizma.py [3] ile yeniden uretilebilir.
    Ayrica README'ye bir tuzak yazildi: build_mechanism.py kendi ciktisinin uzerine ikinci kez kosulamaz (zaten burnu tamamlanmis yuzeye yeniden burun eklemeye calisip Null TopoDS_Shape ile cokuyor). Depodaki STEP'ler Asama 2'nin CIKTISIDIR; "git checkout -- cad/step/ ile temiz duruma donmek" bu yuzden yanlis girdi ur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
2026-09-02 Tam montaj dosyasi Asama 2'de yaziliyor; baska makinede kurulum adimlari eklendi
    tiltrotor_assembly.step yalnizca Asama 1 tarafindan yaziliyordu, yani icinde sadece 23 govde parcasi vardi: 38 mekanizma parcasi ve mentese boslugu acilmis kanat/tailplane/fin yoktu. Onu acan biri me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
    README'ye "Baska bir makinede devam etme" bolumu: cadquery venv, mesh indirme (dogruluk kontrolu icin winglet 417,3 / elevon 125,3 cm3 beklenen degerleriyle), MCP koprusu kurulumu ve mcp<2 pinlemesin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
    [tiltrotor_assembly.step]
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2026-09-03 Asama 2 idempotent yapildi: girdi ciktidan ayrildi + elenen cep yaricapi kodda canliymis
    build_mechanism.py'nin girdisi kendi ciktisiydi: load_part() de export da
    step/parts/ dizinine bakiyordu. Ikinci kosuda betik, burnu zaten silindire
    trasanmis bir yuzeye yeniden burun ekleyip `Null TopoDS_Shape` ile cokuyordu;
    `git checkout -- cad/step/` de kurtarmiyordu cunku depodaki STEP'ler Asama
    2'nin ciktisi.
    DUZELTME 1 -- girdi/cikti ayrimi. Asama 2'nin uzerine yazdigi 10 govde
    (TURETILEN) artik step/parts_pristine/ altindaki dokunulmamis kopyadan
    okunuyor; oraya Asama 1 yaziyor. step/parts/ yalnizca cikti. Liste tek
    kaynakta: Asama 1 onu build_mechanism'dan import ediyor. Kopya eksikse betik
    ne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
    [elevator_left.step, elevator_right.step, elevon_left.step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]
